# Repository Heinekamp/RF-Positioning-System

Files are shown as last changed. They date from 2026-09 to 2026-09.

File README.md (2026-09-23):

# RF-Positioning-System

A cost-effective 2-axis RF positioning system for characterizing antenna directionality in azimuth and elevation, developed as a bachelor project at the EMES chair at the University of Freiburg. Both axes rotate independently around a fixed centre of rotation, controlled by an ESP32 over a standard [SCPI](https://en.wikipedia.org/wiki/Standard_Commands_for_Programmable_Instruments) interface over Ethernet or USB.

<p align="center">
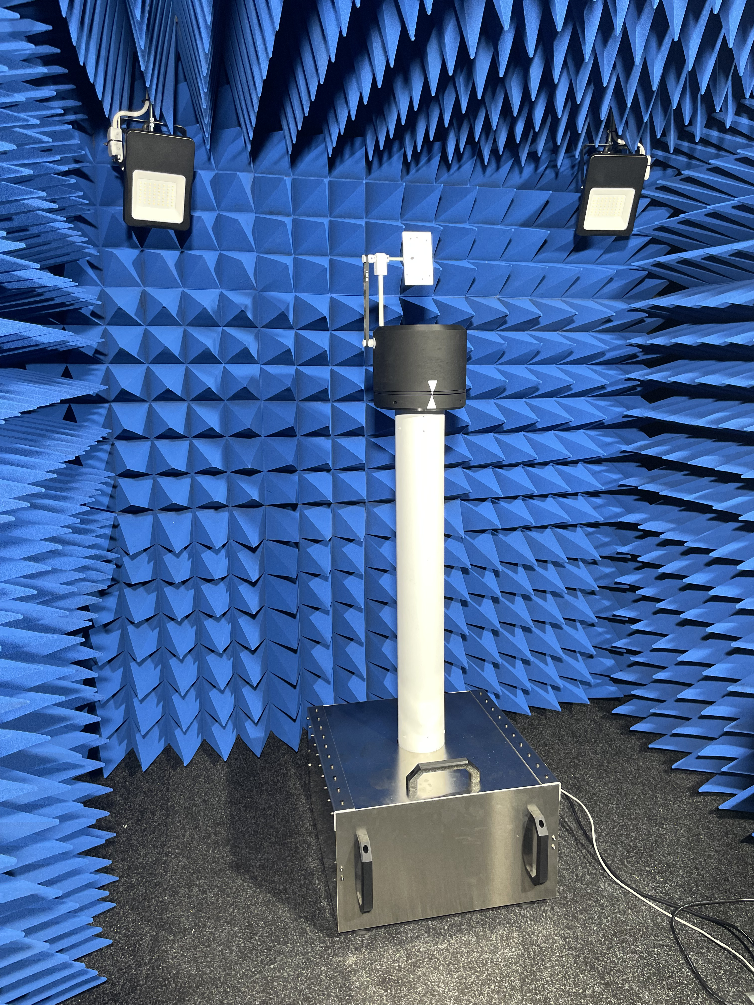
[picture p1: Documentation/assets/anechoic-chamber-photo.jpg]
RF-Positioning-System in an anechoic chamber
  
</p>

## Key Specifications

| Parameter | Value |
|---|---|
| Positioning range | 360° independent rotation, azimuth and elevation |
| Positioning accuracy | 1.0° |
| Positioning speed | 0.1°/s – 180°/s |
| Frequency range | 600 MHz – 6 GHz |
| Payload | 500 g |
| DUT height above base | 1.0 m |
| Base footprint | 40 cm × 40 cm |
| Total weight | ~20 kg |
| Communication | USB, Ethernet (SCPI) |
| Power supply | 12 V DC |

## Measured Performance

Repeatability of both rotation axes, measured with a motion-capture system across 10 repeated full revolutions:

<table>
<tr>
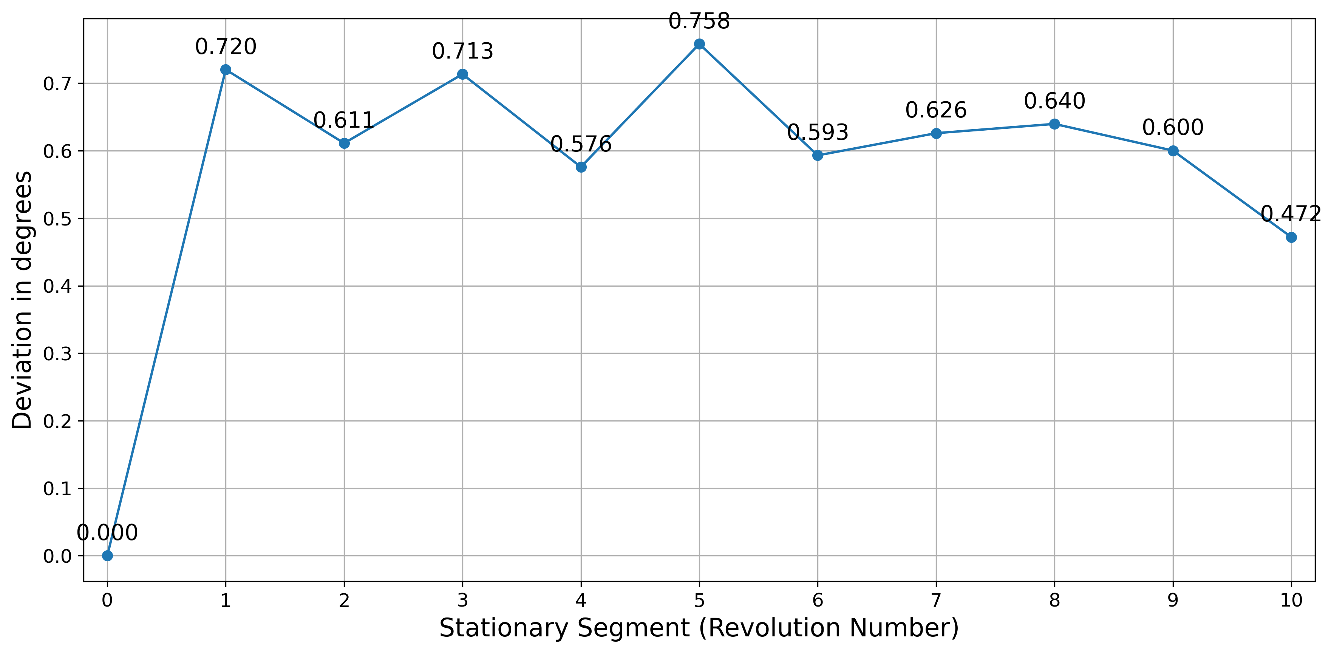
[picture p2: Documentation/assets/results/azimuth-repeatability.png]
Azimuth repeatability
<td width="50%"></td>
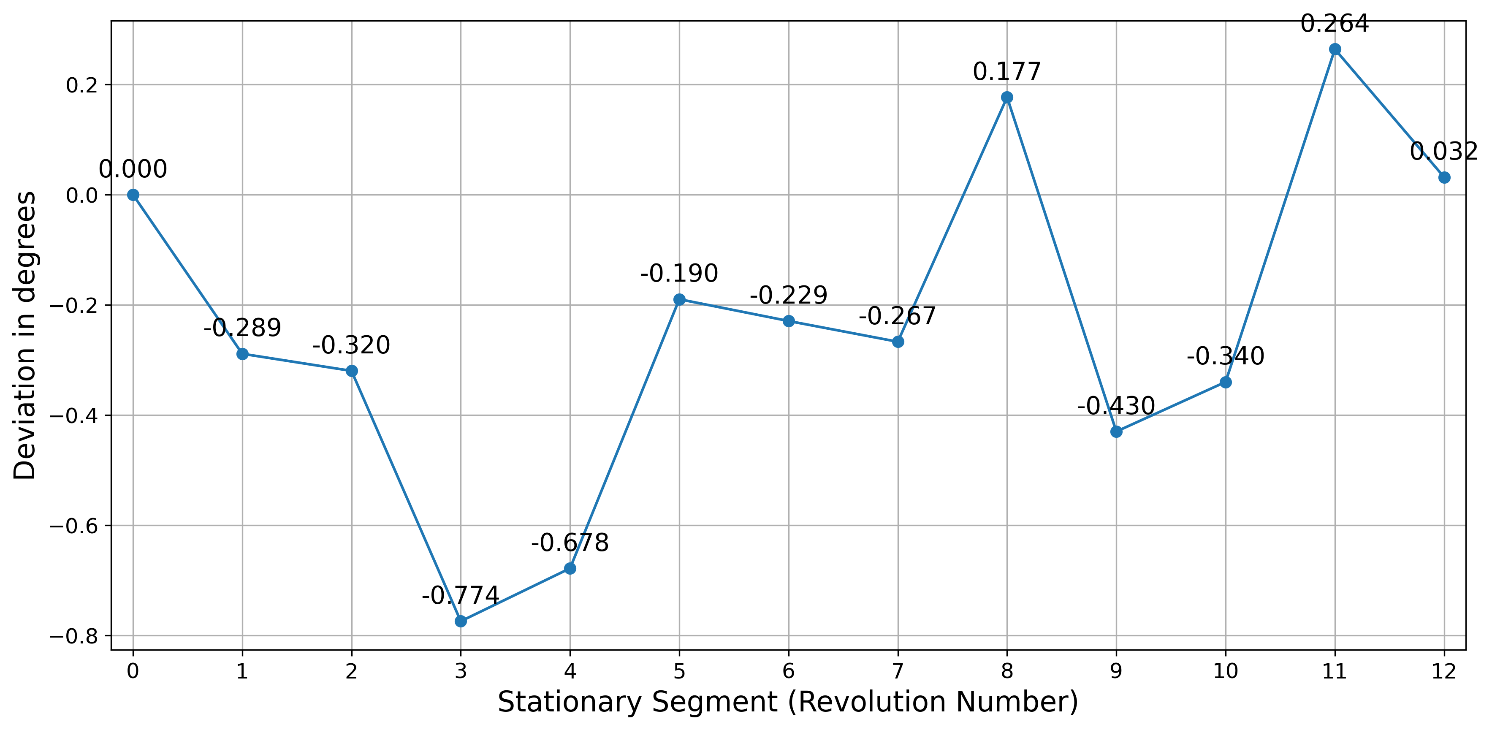
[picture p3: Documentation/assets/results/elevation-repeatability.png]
Elevation repeatability
<td width="50%"></td>
</tr>
<tr>
<td><sub>Azimuth positioning deviation from the commanded angle, measured after each of 10 repeated full revolutions.</sub></td>
<td><sub>Elevation positioning deviation from the commanded angle, measured the same way.</sub></td>
</tr>
</table>

Radiated emissions of the fully assembled, enclosed system were measured with the Ethernet link forced to 10&nbsp;Mbit/s, against 20 dB under the CISPR 11 Class B radiated emissions limit:

<table>
<tr>
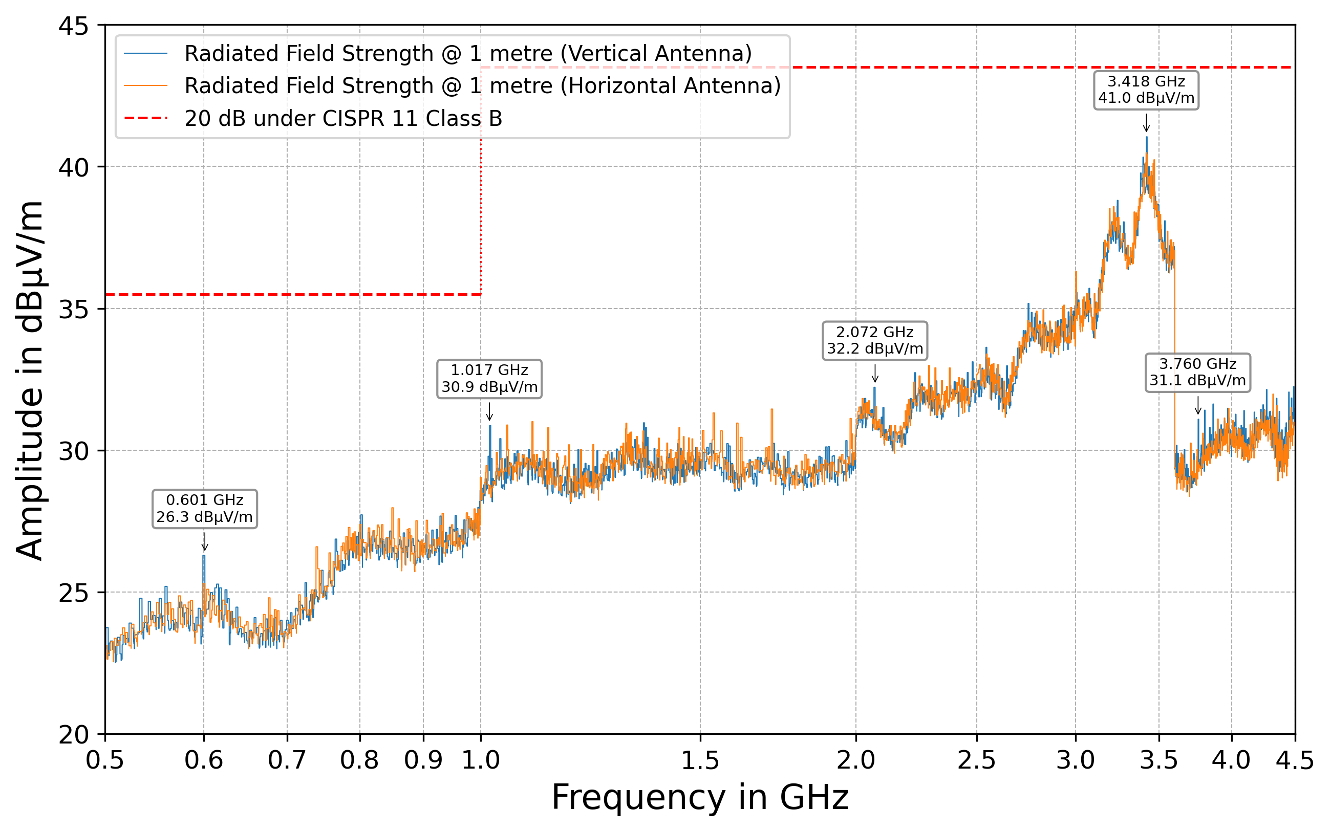
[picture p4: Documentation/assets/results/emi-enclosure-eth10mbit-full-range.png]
Radiated emissions, 0.5-4.5 GHz, enclosed system, 10 Mbit Ethernet
<td width="50%"></td>
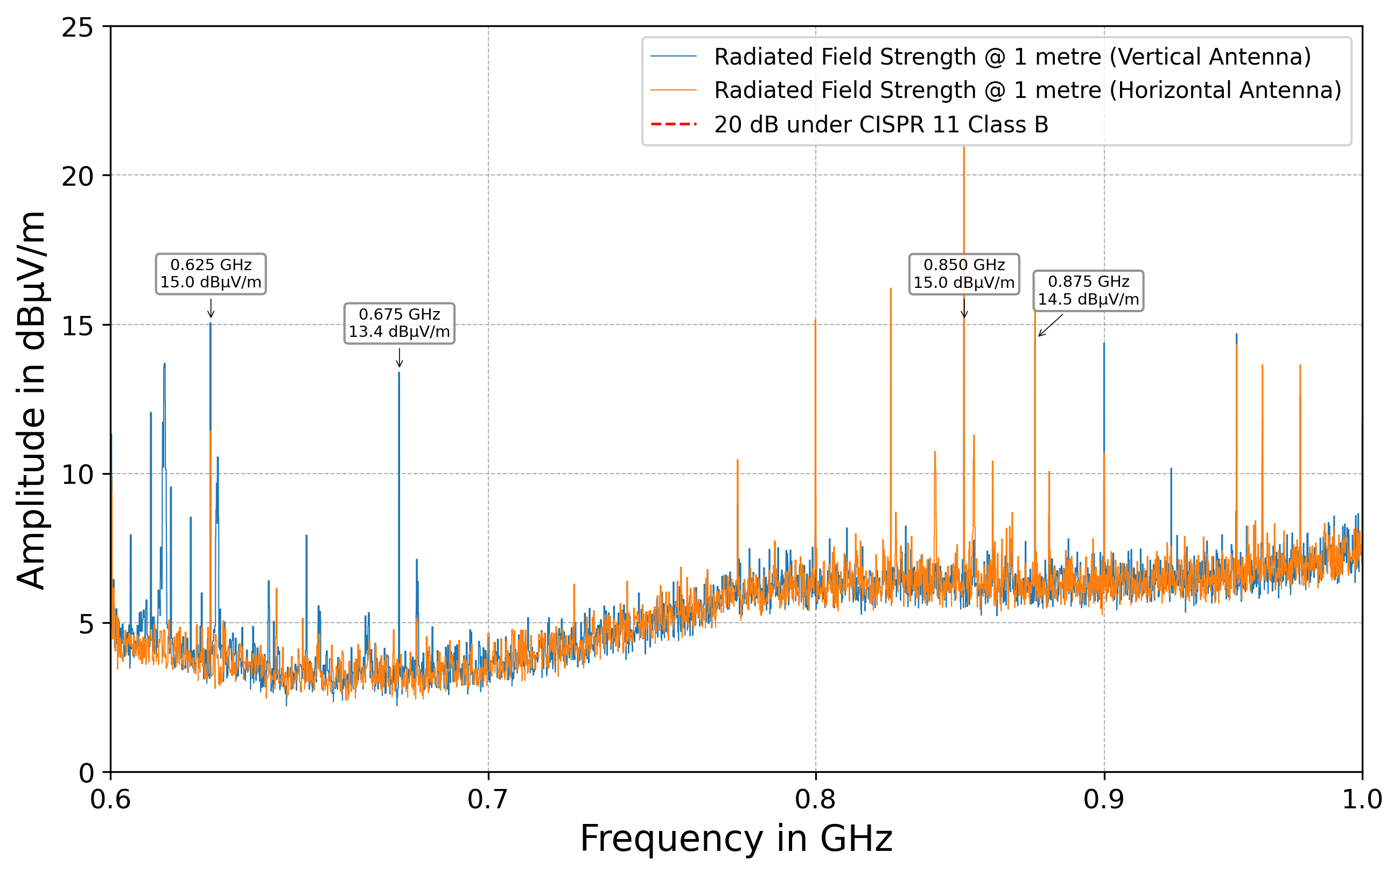
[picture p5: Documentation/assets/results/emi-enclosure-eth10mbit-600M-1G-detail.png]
Radiated emissions, 0.6-1.0 GHz detail
<td width="50%"></td>
</tr>
<tr>
<td><sub>Radiated field strength from 0.5–4.5 GHz, vertical and horizontal antenna polarization, against the CISPR 11 Class B limit.</sub></td>
<td><sub>Detail view of the 0.6–1.0 GHz band from the same measurement — individual emission peaks all remain more than 20 dB below the compliance limit shown at left.</sub></td>
</tr>
</table>

## Hardware

The controller is a custom PCB (KiCad project in [`Electrical/Controller`](Electrical/Controller)) built around an ESP32, driving two TMC2209 stepper drivers over UART. The mechanical design was done in Autodesk Fusion 360; the full CAD model is available in the [Fusion 360 online viewer](https://a360.co/42XAUax).

## Software

The firmware is written in C++ using the Arduino framework in PlatformIO (see [`Code/RF-Positioning-System`](Code/RF-Positioning-System)), and exposes a standards-compliant SCPI command set over Ethernet and USB — see that folder's [readme](Code/RF-Positioning-System/readme.md) for the full command reference and a quick-start example.

Firmware documentation is generated with Doxygen and published [here](https://heinekamp.github.io/RF-Positioning-System/index.html). If the following badge is green, it's up to date: .

## Documentation

The [Service Manual](Documentation/manual/ServiceManual.pdf) covers the system's theory of operation, the full SCPI interface, and maintenance/component-replacement procedures.

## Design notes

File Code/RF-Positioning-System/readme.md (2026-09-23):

# RF-Positioning System

The positioning system uses 2 stepper motors controlled by an ESP32 via SCPI over Ethernet to rotate the DUT in two axes.

## SCPI Command Reference

| Command | Description |
|---|---|
| `*IDN?` | Queries the identification string of the device. |
| `*RST` | Resets the device to its default state. |
| `*OPC?` | Returns 1 once all previously queued commands have completed. |
| `SYSTem:ERRor?` | Retrieves the last error from the error queue. |
| `SYSTem:HELP:HEADers?` | Provides a list of available SCPI commands. |
| `SYSTem:HELP:SYNTax?` | Returns detailed syntax help for a single command header. |
| `SYSTem:VERSion?` | Queries the firmware version of the device. |
| `SYSTem:DEBUG?` | Retrieves debug information from the system. |
| `SYSTem:PRESet` | Resets the system to its preset configuration. |
| `SYSTem:COMMunicate:ETHernet:PORT` | Sets the Ethernet communication port. |
| `SYSTem:COMMunicate:ETHernet:PORT?`| Queries the Ethernet communication port. |
| `SYSTem:COMMunicate:ETHernet:ADDRess` | Sets the IP address of the device. |
| `SYSTem:COMMunicate:ETHernet:ADDRess?`| Queries the IP address of the device. |
| `SYSTem:COMMunicate:ETHernet:MAC` | Sets the MAC address of the device. |
| `SYSTem:COMMunicate:ETHernet:MAC?`| Queries the MAC address of the device. |
| `SYSTem:COMMunicate:ETHernet:DGATeway?`| Queries the default gateway address. |
| `SYSTem:COMMunicate:ETHernet:RESET`| Resets the W5500 Ethernet module and re-initializes the network stack. |
| `CONTRol:ROTation:STEP#` | Jogs the specified axis one full revolution, for testing. |
| `CONTRol:ROTation:PERPetual#`  | Runs the specified axis continuously, for testing. |
| `CONTRol:ROTation:DIRection#`  | Sets the rotation direction for the DUT. |
| `CONTRol:ROTation:DIRection#?` | Queries the current rotation direction of the DUT. |
| `CONTRol:ROTation:RELative#` | Sets the relative position of the DUT. |
| `CONTRol:ROTation:ABSolute#` | Sets the absolute position of the DUT. |
| `CONTRol:ROTation:ABSolute#?`  | Queries the absolute position of the DUT. |
| `CONFigure:MOTor:RMScurrent` | Sets the RMS current for the stepper motors. |
| `CONFigure:MOTor:RMScurrent?`  | Queries the RMS current for the stepper motors. |
| `CONFigure:MOTor:HOLDcurrent`  | Sets the hold current for the stepper motors. |
| `CONFigure:MOTor:HOLDcurrent?` | Queries the hold current for the stepper motors. |
| `CONFigure:MOTor:MICROsteps` | Sets the microstepping configuration for the stepper motors. |
| `CONFigure:MOTor:MICROsteps?`  | Queries the microstepping configuration for the stepper motors. |
| `CONFigure:MOTor:SPEED` | Sets the motion speed used by subsequent moves. |
| `CONFigure:MOTor:SPEED?` | Queries the configured motion speed. |
| `CONFigure:MOTor:ACCELeration` | Sets the motion acceleration used by subsequent moves. |
| `CONFigure:MOTor:ACCELeration?`| Queries the configured motion acceleration. |
| `CONFigure:MOTor:STATus?` | Returns raw TMC2209 driver status registers for both axes. |
| `DIAGnostic:SESSion:LIST?` | Lists live SCPI sessions over Ethernet. |
| `DIAGnostic:SESSion:LOG?` | Lists recent SCPI session closures. |
| `DIAGnostic:SOCKet:LIST?` | Lists the raw state of all W5500 hardware sockets. |
| `DIAGnostic:SYSTem?` | Returns system and reset health diagnostics. |

For the full behavior, parameter ranges, and side effects of each command, see the [Service Manual](../../Documentation/manual/ServiceManual.pdf).

## Documentation
The full firmware documentation is available [here](https://heinekamp.github.io/RF-Positioning-System/index.html).

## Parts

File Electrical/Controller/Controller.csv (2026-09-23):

Reference | Value | Footprint | Datasheet | Qty | DNP | Exclude from BOM | Exclude from Board
A1 | ESP32 | FootprintLibrary:Adafruit_Feather_ESP32 | https://cdn-learn.adafruit.com/downloads/pdf/adafruit-huzzah32-esp32-feather.pdf | 1
C1,C10 | 2200uF | FootprintLibrary:WCAP-ATG8_16X25_DXL_ | ~ | 2
C2,C3,C5,C6,C13,C19 | 100nF | Capacitor_SMD:C_1206_3216Metric_Pad1.33x1.80mm_HandSolder | ~ | 6
C4,C7,C11 | 1000uF | FootprintLibrary:WCAP-ATUL_13X25_DXL_ | ~ | 3
C8 | 1uF | Capacitor_SMD:C_1210_3225Metric_Pad1.33x2.70mm_HandSolder | ~ | 1
C9,C15,C16 | 10uF | Capacitor_SMD:C_2220_5750Metric_Pad1.97x5.40mm_HandSolder | ~ | 3
C12,C17,C20 | 100uF | FootprintLibrary:WCAP-ATG8_6.3X11_DXL_ | ~ | 3
C14,C18 | 10nF | Capacitor_SMD:C_1206_3216Metric_Pad1.33x1.80mm_HandSolder | ~ | 2
C21 | 1nF | Capacitor_SMD:C_1206_3216Metric_Pad1.33x1.80mm_HandSolder | ~ | 1
D1 | SMCJ36CA | Diode_SMD:D_SMC_Handsoldering | ~ | 1
FL1,FL2,FL3,FL4 | 744235900 | FootprintLibrary:WE-CNSW_1812 | https://www.we-online.com/components/products/datasheet/744235900.pdf | 4
J1 | 12-28V IN | FootprintLibrary:BarrelJack_Wuerth_6941xx301002 | ~ | 1
J2 | Screw_Terminal_01x02 | FootprintLibrary:691502710002 | ~ | 1
J3,J4 | RJ45_LED_Shielded | FootprintLibrary:Wuerth 615008137421 | ~ | 2
L1,L2,L3,L4 | 600Ω@100 MHz | Capacitor_SMD:C_2220_5750Metric_Pad1.97x5.40mm_HandSolder | ~ | 4
Q1 | DMT10H015LK3-13 | Package_TO_SOT_SMD:TO-252-3_TabPin2 | https://www.diodes.com/assets/Datasheets/DMT10H015LK3.pdf | 1
Q2 | DMN53D0LW-7 | Package_TO_SOT_SMD:SOT-323_SC-70_Handsoldering | https://www.onsemi.com/pub/Collateral/BSS138-D.PDF | 1
R1 | 1k | Resistor_SMD:R_1206_3216Metric_Pad1.30x1.75mm_HandSolder | ~ | 1
R2 | 6.04k | Resistor_SMD:R_1206_3216Metric_Pad1.30x1.75mm_HandSolder | ~ | 1
R3 | 10k | Resistor_SMD:R_1206_3216Metric_Pad1.30x1.75mm_HandSolder | ~ | 1
R4 | 604k | Resistor_SMD:R_1206_3216Metric_Pad1.30x1.75mm_HandSolder | ~ | 1
R5 | 76.8k | Resistor_SMD:R_1206_3216Metric_Pad1.30x1.75mm_HandSolder | ~ | 1
R6 | 20k | Resistor_SMD:R_1206_3216Metric_Pad1.30x1.75mm_HandSolder | ~ | 1
U1,U2 | TMC2209 | FootprintLibrary:BTT-TMC2209-V1.3 | https://github.com/bigtreetech/BIGTREETECH-TMC2209-V1.2/blob/master/manual/TMC2209-V1.2-manual.pdf | 2
U3 | TPS26631PWP | Package_SO:HTSSOP-20-1EP_4.4x6.5mm_P0.65mm_EP3.4x6.5mm_Mask2.75x3.43mm_ThermalVias_HandSolder | https://www.ti.com/lit/ds/symlink/tps2663.pdf | 1
U5 | LD1086D2M33TR | FootprintLibrary:TO-220-3_Vertical-v8508a | https://www.st.com/resource/en/datasheet/ld1086.pdf | 1

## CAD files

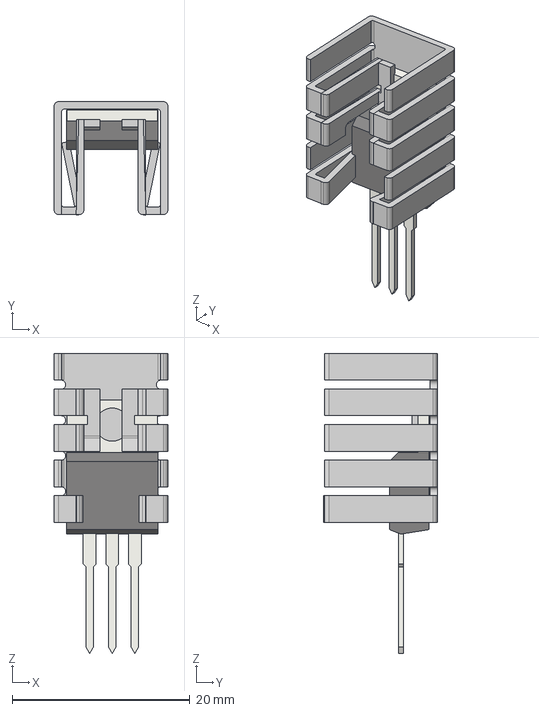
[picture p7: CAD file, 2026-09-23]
Electrical/Controller/3D-models/TO-220-3_Vertical v8508a.step
12.8 x 12.8 x 33.8 mm

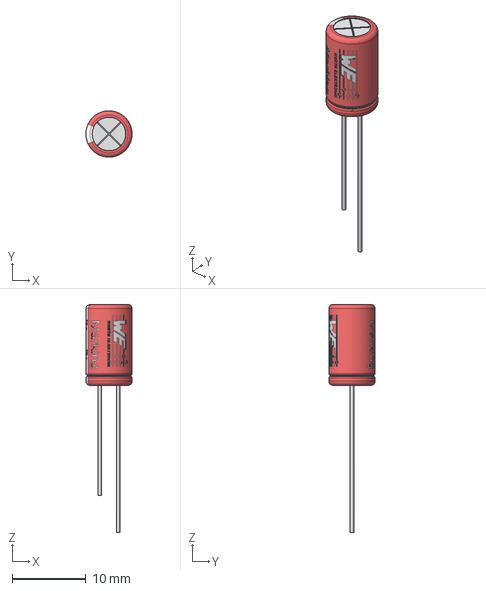
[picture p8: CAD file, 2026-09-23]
Electrical/Controller/3D-models/Download_STP_86001xx730xx (rev1).stp
6.29 x 6.30 x 31.0 mm

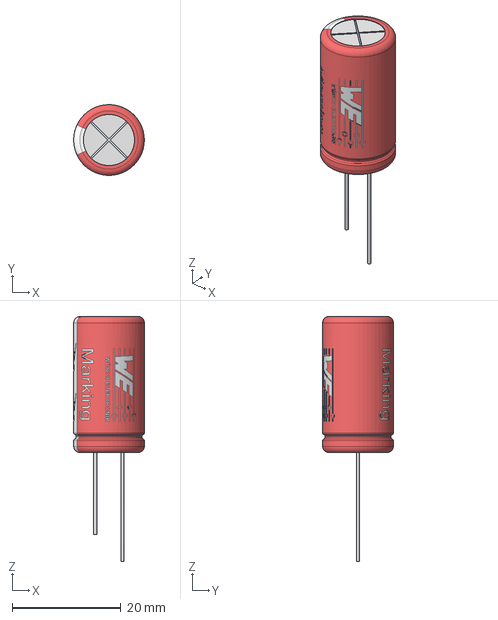
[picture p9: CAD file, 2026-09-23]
Electrical/Controller/3D-models/Download_STP_860040x7801x (rev1).stp
13.0 x 13.0 x 45.0 mm

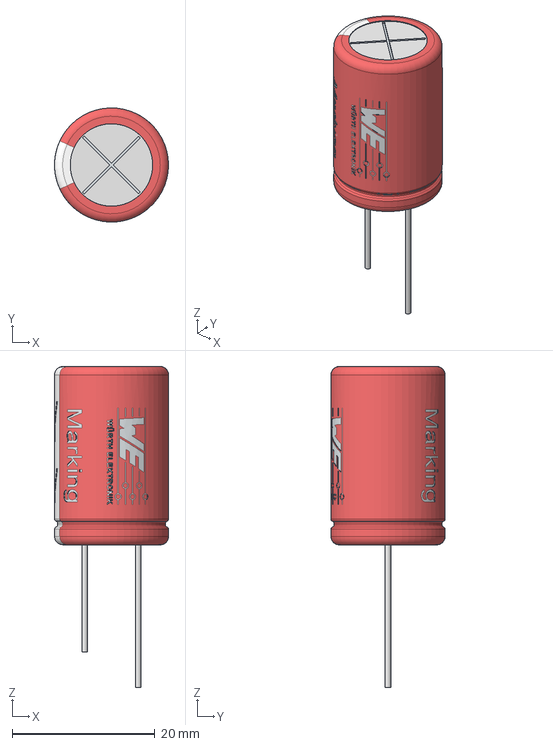
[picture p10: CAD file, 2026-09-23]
Electrical/Controller/3D-models/Download_STP_86001xx800xx (rev1).stp
16.0 x 16.0 x 45.0 mm

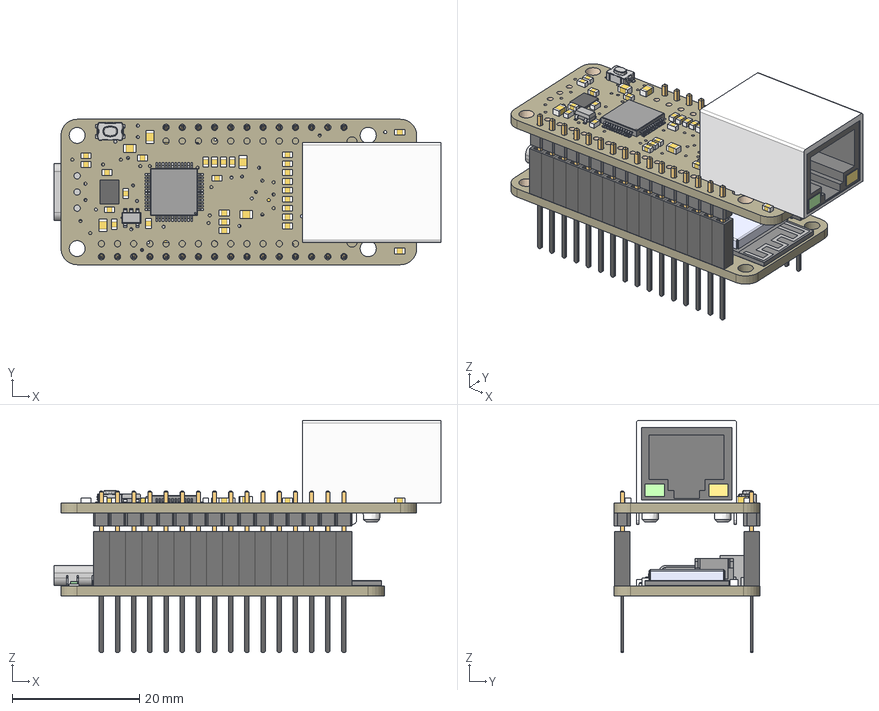
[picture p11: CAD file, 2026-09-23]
Electrical/Controller/3D-models/5400 ESP32 Feather V2 v2.step
60.8 x 22.9 x 36.5 mm
Board
10uF x 7
AP2112-3.3 x 2
MBR540
JSTPH
MCP73831T-2ACI/OT
RED x 2
1uF x 15
KMR2 x 2
DMG3415U
47K x 2
ESP32-PICO-MINI-02MINI
WS2812B3535
STEMMA_I2C_QTRA
TPB1,27 x 2
USB Type C
CP2102N-24
DUAL NPN
Komponente1 x 12
Komponente2 x 12
Komponente1_1 x 16
Komponente2_1 x 16
Board_1
W5500
RB1-125BAG1A
25MHz
10K x 27
ferrite x 5
74AHC1G125
KMR2_1
6130xx11121_PIN x 12
6130xx11121_PIN_1 x 16

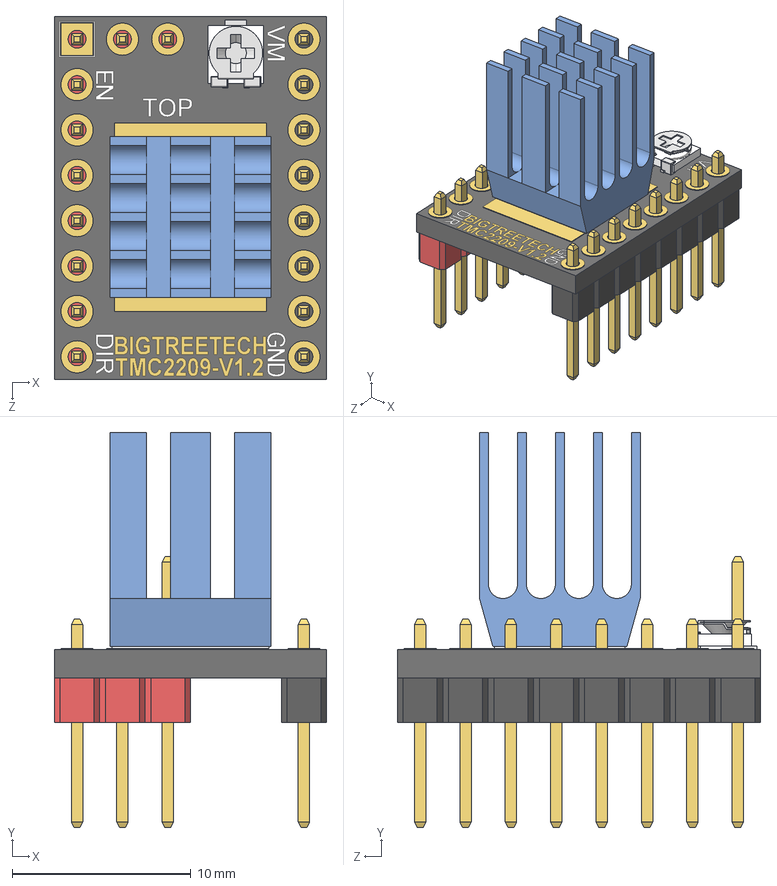
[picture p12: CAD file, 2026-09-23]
Electrical/Controller/3D-models/BTT TMC2209-V1.2.STEP
15.2 x 22.1 x 20.3 mm
TMC2209_board
Pin_Header_1x2_red
Pin_Header_1x8_red
Pin_Header_1x8_black
EVM-3E___ _________
TMC2209_heatsink

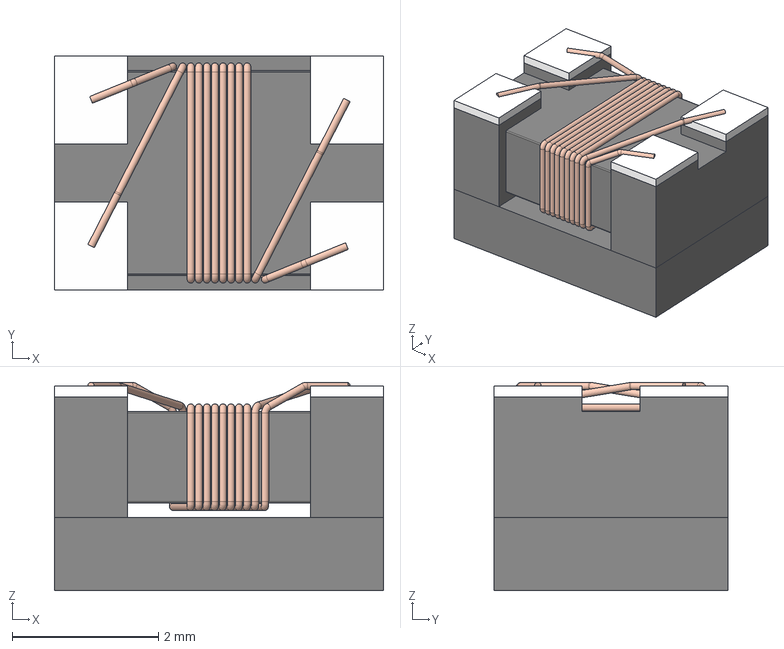
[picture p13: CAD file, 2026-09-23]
Electrical/Controller/3D-models/WE-CNSW_1812.step
4.50 x 3.20 x 2.85 mm

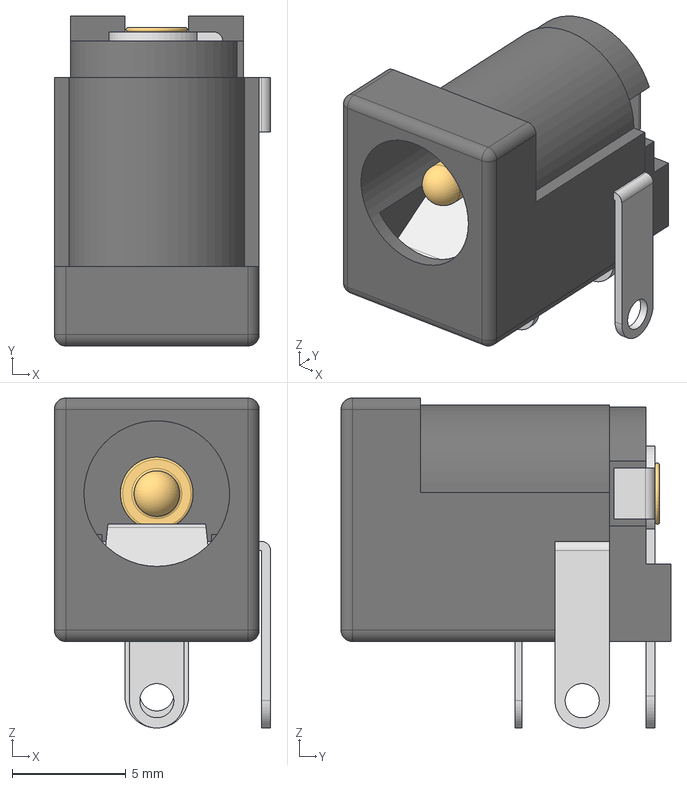
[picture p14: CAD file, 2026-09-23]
Electrical/Controller/3D-models/694106301002 (rev1).stp
9.50 x 14.5 x 14.5 mm
6941xx301002
694106301002_PinContact
6941xx301002_Back
6941xx301002_PinContact2
6941xx301002_PinLame
6941xx301002_PinBis

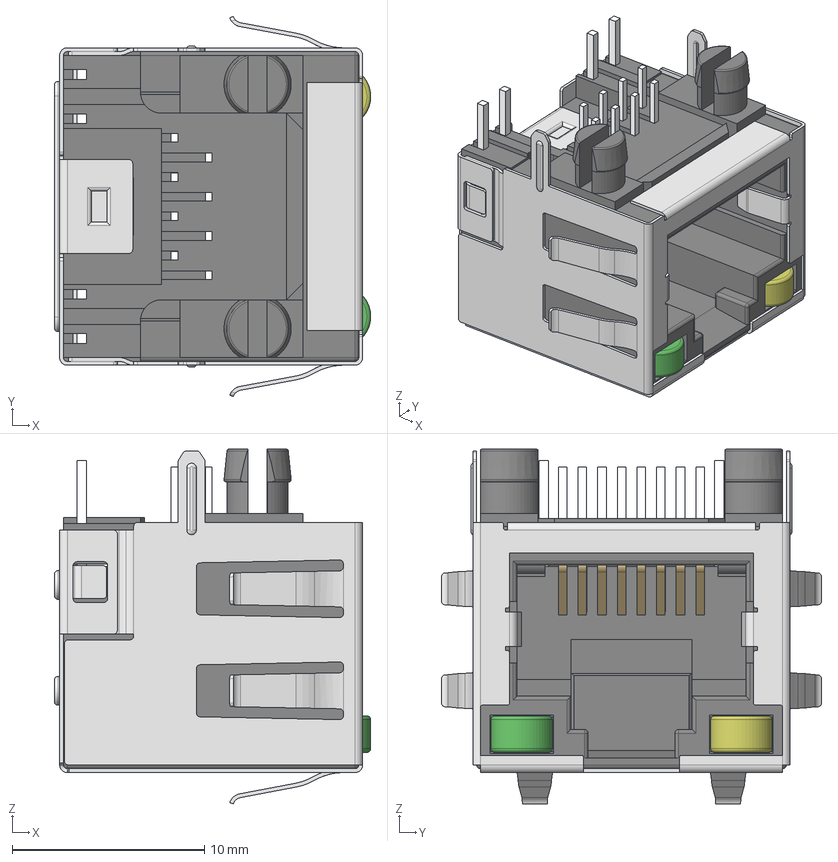
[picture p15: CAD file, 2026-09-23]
Electrical/Controller/3D-models/615008137421.step
16.4 x 19.8 x 18.4 mm
Shielding
Pin_short x 4
Gehäuse
LED_yellow
Halter_Pin
LED_green
Deckel
Pin_long x 4

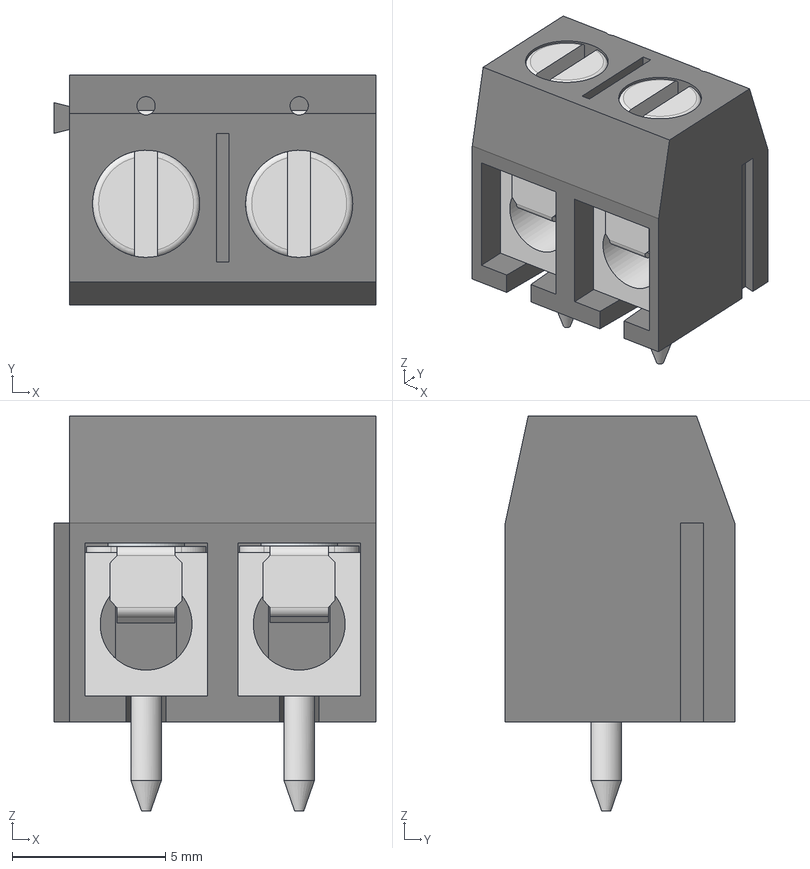
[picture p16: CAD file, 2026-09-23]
Electrical/Controller/3D-models/691502710002 (rev1).stp
10.5 x 7.50 x 12.9 mm
6915027100xx_CAGE x 2
6915027100xx_PIN x 2
6915027100xx_VIS x 2

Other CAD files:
Electrical/Controller/3D-models/691502710002.step

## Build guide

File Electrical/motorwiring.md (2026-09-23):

Ethernet to JST PH motor connector wiring guide:

Pin 1   | Orange + Green
Pin 2   | X
Pin 3   | Brown + Blue / White
Pin 4   | Orange / White + Green / White
Pin 5   | X
Pin 6   | Brown / White + Blue

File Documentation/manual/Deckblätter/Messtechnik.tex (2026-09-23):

%% Titlepage Messtechnik
\begin{titlepage}
    \vspace*{-2cm}
    \begin{centering}
        \begin{minipage}{1.2\textwidth}
            \hspace{-0cm}
            \begin{minipage}[b]{0.25\textwidth}
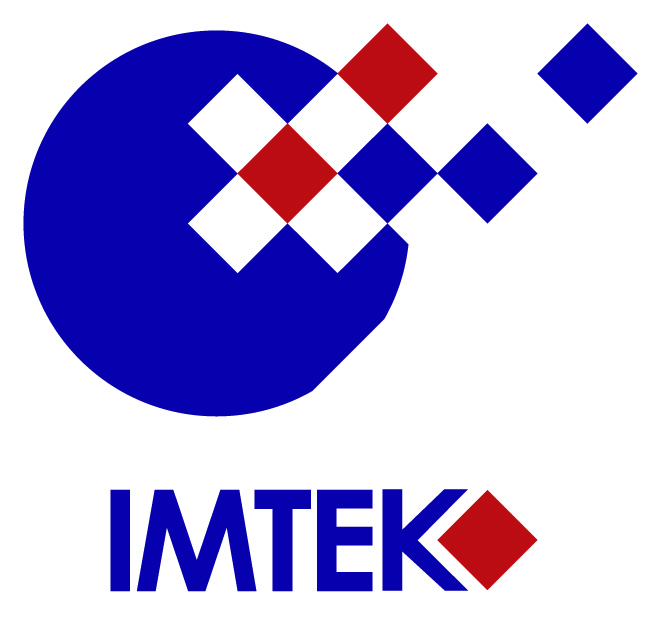
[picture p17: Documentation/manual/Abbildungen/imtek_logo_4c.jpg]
                
            \end{minipage}
            \hspace*{2.3cm}
            \begin{minipage}[t]{0.9\textwidth}
                
            \end{minipage}
        \end{minipage}
        \vspace{2cm}
        \newline
        {\Huge RF Positioning System \par}
        	\vspace{0.5cm}
        {\huge Service Manual \par}
        	\vspace{0.5cm}
    \end{centering}

    \vspace{0cm}
    \begin{center}
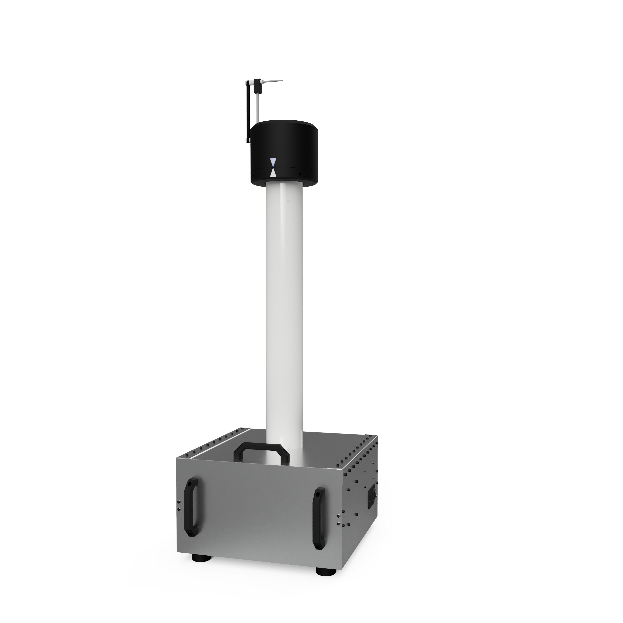
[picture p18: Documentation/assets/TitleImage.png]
        
    \end{center}

    \hspace*{-0.4cm}
    \renewcommand{\arraystretch}{2}
    \begin{tabular}{p{0.2\textwidth} p{0.8\textwidth}}
        \Large Date: & \Large \today\\
        \Large Author: & \Large Max Heinekamp \\
    \end{tabular}
    \enlargethispage{2\baselineskip}
    \renewcommand{\arraystretch}{1}
    \vspace{1cm}
    \newline
    \normalsize 
    %[Abstract here]
    \vfill
\end{titlepage}

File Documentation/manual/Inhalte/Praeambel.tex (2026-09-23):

%% Input Codec
\usepackage[utf8]{inputenc}

%% Sprache (Silbentrennung etc.)
\usepackage[british]{babel}

%% Font Codec
\usepackage[T1]{fontenc}

\usepackage[useregional=numeric]{datetime2}

\usepackage[lowtilde]{xurl}

%% Literaturverzeichnis
\usepackage[style=numeric-comp,sorting=none]{biblatex}
%\usepackage[english=guillemets]{csquotes}
\addbibresource{Literaturverzeichnis/Literaturverzeichnis.bib} 
\setcounter{biburllcpenalty}{7000}
\setcounter{biburlucpenalty}{8000}

%% Bearbeitung von Kopf und Fußzeile
\usepackage{fancyhdr}
\fancyhf{}
\pagestyle{fancy}
\fancyheadoffset{0cm}
\fancyfoot[R]{\thepage}

%% Paket für die Verwendung von Einheiten
\usepackage[separate-uncertainty=true]{siunitx}

%% "Punktlinien" im Inhaltsverzeichnis
\usepackage{tocloft}
\renewcommand{\cftsecleader}{\cftdotfill{\cftdotsep}}

%% Seitenabstaende
\usepackage[left=2.5cm,right=2.5cm,top=1.25cm,bottom=1.25cm,includeheadfoot]{geometry} 

%% Math Features
\usepackage{amsmath}
\usepackage{amsfonts}
\usepackage{amssymb}

%% Grafik Features
\usepackage{graphicx}
\usepackage{tikz}
\usetikzlibrary{positioning}
\usepackage[inkscapeformat=png]{svg}

%% Zeilenabstand 1,5-fache Kegelhöhe
\usepackage{setspace} \onehalfspacing

%% Größerer Abstand zwischen Tabellenüberschrift und Tabelle
\usepackage{caption}
\captionsetup[table]{position=above,skip=0.5cm}

%% Nicht einrücken
\setlength{\parindent}{0em}

%% Bearbeitung von Tabellen
\usepackage{booktabs}
\usepackage{ltablex} %was tabularx
\keepXColumns   % used with ltablex and geometry

\usepackage{wrapfig}
\usepackage{float}

%% Syntax Highlighting
\usepackage{listings}

%% Links und Verweise
\usepackage[hidelinks]{hyperref}

\definecolor{codegreen}{rgb}{0,0.6,0}
\lstdefinestyle{mystyle}{
    basicstyle=\ttfamily\footnotesize,
    backgroundcolor=\color{white},
    commentstyle=\color{codegreen},
    keywordstyle=\color{blue},
    numberstyle=\tiny\color{gray},
    stringstyle=\color{red},
    breakatwhitespace=false,         
    breaklines=true,                 
    captionpos=b,                    
    keepspaces=true,                 
    numbers=left,                    
    numbersep=5pt,                  
    showspaces=false,                
    showstringspaces=false,
    showtabs=false,                  
    tabsize=2
}

\lstset{style=mystyle}

%Subfigures
\usepackage{subcaption}

%urldate
\DeclareFieldFormat{urldate}{%
  (Accessed: \thefield{urlday}.%
  {\thefield{urlmonth}}.%
  \thefield{urlyear}\isdot)}

\usepackage{mdframed}
\usepackage{csquotes}

\usepackage{pdfpages}

\usepackage{array}
\newcolumntype{L}{>{\centering\arraybackslash}m{4.5cm}}
\newcolumntype{C}{>{\centering\arraybackslash}m{2.5cm}}

\usepackage{multicol}

\usepackage[most]{tcolorbox}
\usepackage{fontawesome5} % for icons
\usepackage{xcolor}

% Generic github-style box template
\tcbset{
  githubbox/.style 2 args={
    standard jigsaw,
    opacityback=0,
    opacityframe=0,
    enhanced,
    sharp corners,
    boxrule=0pt,
    colback=white,
    colframe=white,
    borderline west={2pt}{0pt}{#1},
    before skip=10pt, after skip=10pt,
    % Remove title bar, place title inside box
  }
}

% Macro to render colored title line inside the box
\newcommand{\githubboxtitle}[2]{%
  {\color{#1}\bfseries #2}\\[2pt]
}

% Define individual boxes using the style, with title inside
\newtcolorbox{notebox}{
  githubbox={blue}{},
  before upper={\githubboxtitle{blue}{\faInfoCircle\quad Note}}
}

\newtcolorbox{tipbox}{
  githubbox={green!60!black}{},
  before upper={\githubboxtitle{green!60!black}{\faLightbulb[regular]\quad Tip}}
}

\newtcolorbox{importantbox}{
  githubbox={violet}{},
  before upper={\githubboxtitle{violet}{\faExclamationCircle\quad Important}}
}

\newtcolorbox{warningbox}{
  githubbox={orange!90!black}{},
  before upper={\githubboxtitle{orange!90!black}{\faExclamationTriangle\quad Warning}}
}

\newtcolorbox{cautionbox}{
  githubbox={red}{},
  before upper={\githubboxtitle{red}{\faTimesCircle\quad Caution}}
}

\usepackage{enumitem}

% Assembly instructions box
% Define part colors
\definecolor{part1}{RGB}{255, 85, 85}
\definecolor{part2}{RGB}{85, 170, 255}
\definecolor{part3}{RGB}{85, 255, 85}
\definecolor{part4}{RGB}{255, 170, 0}

% Tool pictogram mockups
\newcommand{\flathead}[1]{%
  \renewcommand{\arraystretch}{0.25}
  \begin{tabular}{c}
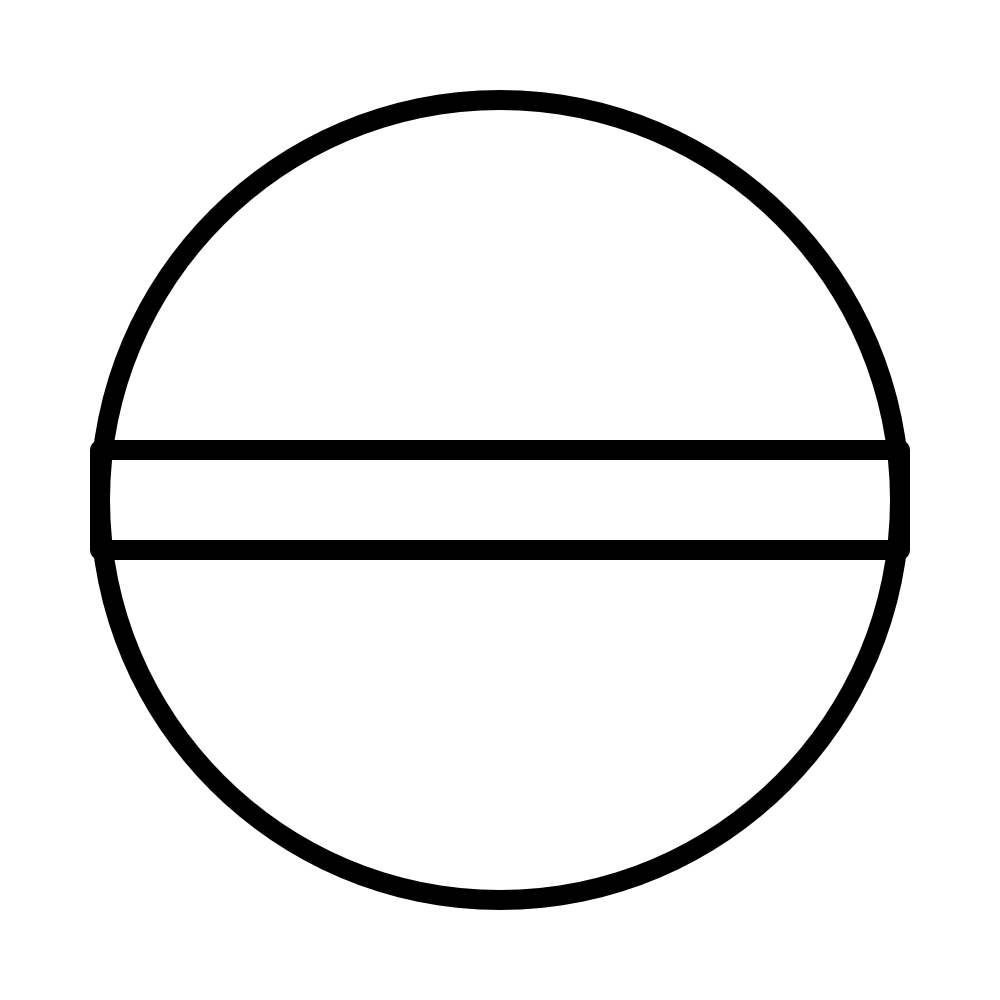
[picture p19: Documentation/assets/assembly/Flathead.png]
     \\
    \tiny #1
  \end{tabular}
}
\newcommand{\hexkey}[1]{%
  \renewcommand{\arraystretch}{0.25}
  \begin{tabular}{c}
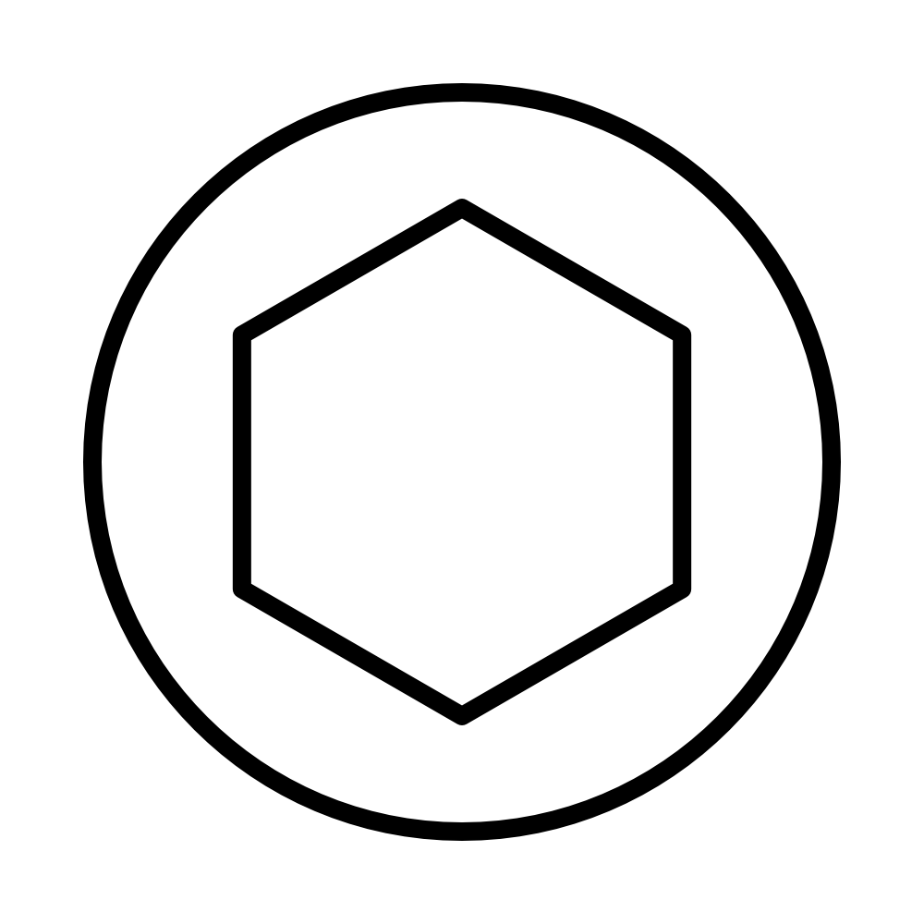
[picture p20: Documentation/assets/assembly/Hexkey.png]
     \\
    \tiny #1
  \end{tabular}
}

\newcommand{\torx}[1]{%
  \renewcommand{\arraystretch}{0.25}
  \begin{tabular}{c}
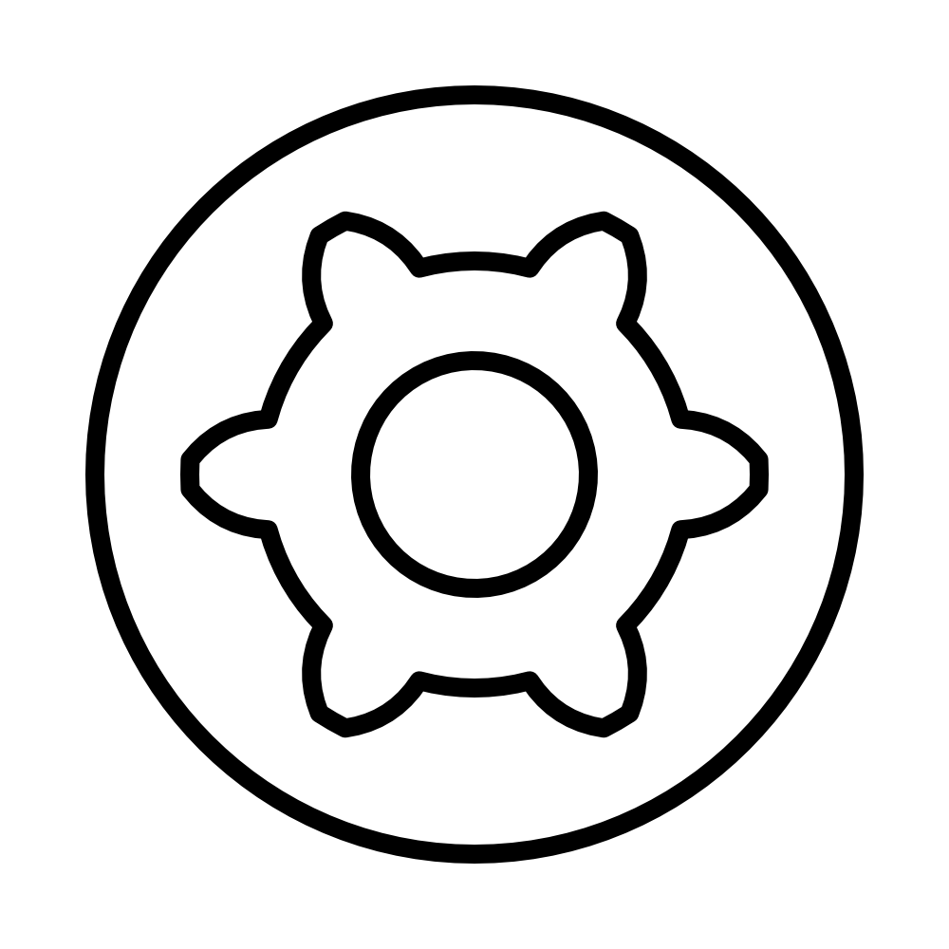
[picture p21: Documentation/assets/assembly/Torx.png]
     \\
    \tiny #1
  \end{tabular}
}

\newcommand{\smartphone}[1]{%
  \renewcommand{\arraystretch}{0.25}
  \begin{tabular}{c}
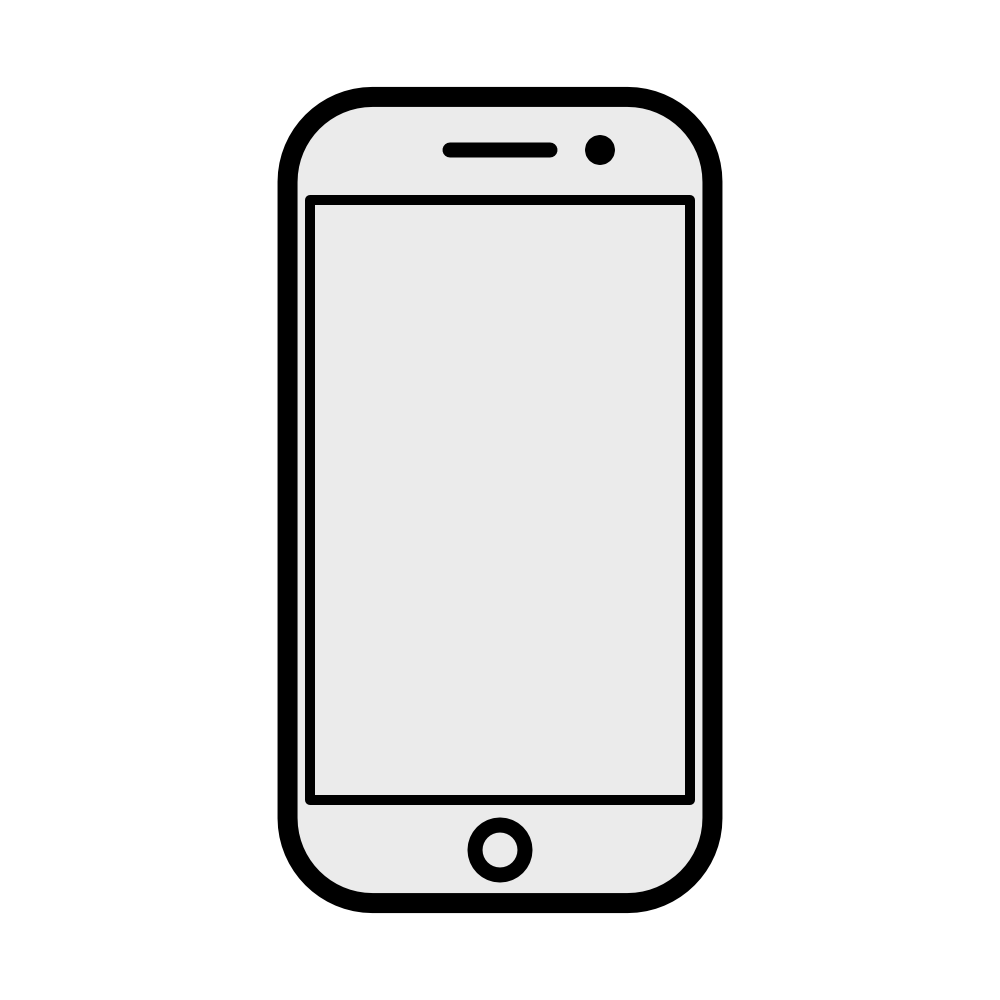
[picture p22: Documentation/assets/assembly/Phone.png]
     \\
    \tiny #1
  \end{tabular}
}

% Colored bullet item command
\newcommand{\partitem}[2]{\item[\textcolor{#1}{\textbullet}] #2}

% Assembly step macro
\newcommand{\assemblystep}[4]{%
  \noindent
  \begin{tikzpicture}[remember picture]
    % Outer box
    \draw (0,0) rectangle (16,-10);

    % Step number
    \node[anchor=north west] at (0,-0.2) {\textbf{Step #1}};

    % Tools section
    \node[anchor=north west] at (10.3,0.1) {#3};
    \draw (10,0) -- (10,-1) -- (16,-1);

    % Image area
    \draw (0,-1) -- (10,-1) -- (10,-10);
    \node at (5,-5.5) {};

    % Parts and instructions node
    \node[anchor=north west, text width=5.5cm, align=left] at (10.3,-1) {\small{#4}};
  \end{tikzpicture}
}

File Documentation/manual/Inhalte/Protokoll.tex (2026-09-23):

\fancyhead[L]{RF-Positioning System}
\newpage

\section{Introduction}

This document describes the RF-Positioning System, a cost-effective two-axis antenna positioner with a small footprint, intended for characterizing antenna directionality in azimuth and elevation around a fixed centre of rotation. It covers the system's operating principles, its SCPI interface, and the maintenance and service procedures needed to keep it running.

\section{Specifications \& Requirements}

The RF-Positioning System is built to the following specifications \cite{timothy_foley_low-cost_2017, maturo_gmbh_ota_nodate, innco_systems_gmbh_de3600_nodate, microwave_vision_group_light_2025, ets-lindgren_2117_nodate, tdk_rf_solutions_3-dimensional_2024}:
\begin{itemize}
    \item \textbf{Positioning Range:} \SI{360}{\degree} independent rotation in azimuth and elevation
    \item \textbf{Positioning Accuracy:} \SI{1.0}{\degree}
    \item \textbf{DUT Height above Base:} \SI{1.0}{\meter}
    \item \textbf{Base Footprint:} \SI{40}{\centi\meter} x \SI{40}{\centi\meter}
    \item \textbf{Minimum Positioning Speed:} \SI{0.1}{\degree/\second}
    \item \textbf{Maximum Positioning Speed:} \SI{180}{\degree/\second}
    \item \textbf{Payload:} \SI{500}{\gram} 
    \item \textbf{Frequency Range:} \SI{600}{\mega\hertz}~\textendash~\SI{6}{\giga\hertz} 
    \item \textbf{Communication:} USB, Ethernet
    \item \textbf{Power Supply:} \SI{12}{\volt} DC
    \item \textbf{Total Weight:} \SI{\sim 20}{\kilo\gram}
\end{itemize}

\section{Theory of Operation}

\subsection{Mechanical Design}
Most commercial designs opt to only implement elevation rotation on the mast and use a large turntable to provide azimuth rotation. In order to maintain a smaller footprint, while still keeping the centre of mass of the DUT constant during rotation, this design has moved the azimuth rotation to the top of the mast. Figure \ref{fig:mechanical_design} shows how this is achieved using two shafts to transfer the rotation from the motors to the top of the mast. 

In the base unit, both shafts are kept in place by a set of bearings. The stepper motors are coupled to the shafts using a set of timing belts. 

The shaft for the azimuth rotation is mounted off centre and has a gear mounted to the top end, which interfaces with a negative gear on the inside of the head unit. Meanwhile, the elevation shaft is mounted in the centre of the mast aligned with the azimuth axis of rotation. At the top of the shaft, a set of bevel gears is used to transfer the rotation out of the side of the head unit. From there, another timing belt is used to transfer the rotation to the top of the secondary mast, where the DUT is mounted.

The main drawback to this design is that the elevation rotation is coupled to the azimuth rotation. This adds some complexity to the control algorithm, as in order to maintain the elevation angle when the azimuth angle is changed, the elevation motor needs to be moved in sync with the azimuth motor. 

\begin{figure}[h!]
    \centering
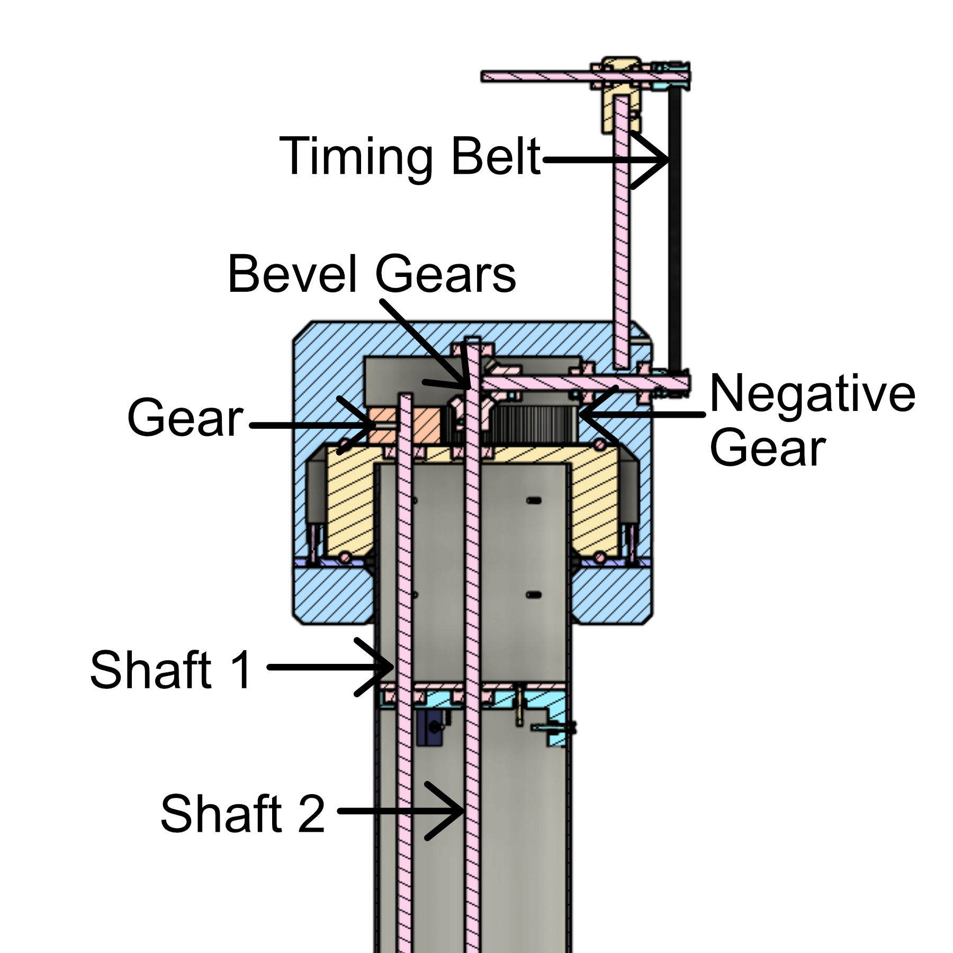
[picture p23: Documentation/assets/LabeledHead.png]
    
    \caption{Labelled rotation mechanism in the head unit.}
    \label{fig:mechanical_design}
\end{figure}

\subsection{Choice of Materials}
Under the main objective of using only non-conductive materials outside of the base, material choice was driven by the need to balance a low dielectric constant, to minimize interference with RF measurements, with high mechanical strength.

Polylactic Acid (PLA) was chosen for the 3D printed components, which make up most of the head unit, as well as the shaft stabilizers in the pipe. In 2018, Veseleý et al. measured in \cite{vesely_evaluation_2018} that 3D Printed PLA had a dielectric constant $\epsilon_r$ of slightly less than 2.0, for frequencies from 1kHz to 100kHz, with the trend showing a slight decrease for higher frequencies. It should be noted that these values were measured for a frequency range much lower than the RF frequencies used in this project. However, it is assumed that the dielectric constant will not increase significantly for higher frequencies. Additionally, these values were measured for parts with an infill density of \SI{100}{\percent}, while the parts in this project were printed with an infill density of \SI{20}{\percent}. This should significantly reduce the dielectric constant, as \SI{80}{\percent} of the material is replaced with air. Therefore, an $\epsilon_r$ of 2.0 should give a sufficient worst case estimate for the dielectric constant of the 3D printed parts.

For the printed parts fixing the pipe and the motors to the base, a higher strength material was required. As this would be in the shielded base, the dielectric constant is not critical. For this reason, a polyamide with carbon fibre reinforcing particles (PA-CF) was chosen for the additional strength and rigidity. Compared to the PLA, the PA-CF has significantly larger flexural modulus\footnote{Stiffness of the material when bent, a larger value indicates a stiffer material.} (\SI{8.0}{\giga\pascal} vs. \SI{3.2}{\giga\pascal}) as well as a higher charpy impact strength\footnote{The charpy impact strength describes the amount of energy a material can absorb under flexural shock (being struck by a hammer) before breaking.} (\SI{60}{\kilo\joule\per\square\metre} vs. \SI{13}{\kilo\joule\per\square\metre})\cite{formfutura_bv_technical_2023},\cite{prusa_polymers_technical_2022}. It should however be noted, that the conductive carbon fibres in the PA-CF, which provide the additional stiffness, may have a negative effect on the signal integrity, which makes the material unsuitable for use in the RF path.

Another area where material choice was critical, are the fasteners used in the head unit. For the majority of these fasteners, polyamide screws were chosen, as they are commercially available at a low cost. Polyamide typically has a dielectric constant of 3.5 at \SI{1}{\mega\hertz} in dry conditions. However, the material is highly hygroscopic, which means that this value increases up to 7.0 at \SI{50}{\percent} humidity \cite{rolec_gehause-systeme_gmbh_polyamid_pa6_en-_nodate}. This is not ideal, however still significantly better than using metal screws. If there were commercially available screws made from a less hygroscopic material that still fulfil the strength requirements this would be an area where the design could be further improved. For the grub screws used to secure the gears to the shafts, a plastic screw would not provide sufficient strength to keep the gears from slipping on the shaft. For this reason, steel screws with a diameter of \SI{4}{\milli\metre} and a length of \SI{5}{\milli\metre} were chosen. The dimensions here are critical, as the longest side is equivalent to $\lambda/10$ for the maximum frequency of \SI{6}{\giga\hertz} used in this project, which means that it will not significantly interfere with the RF measurements. This is due to the fact that objects smaller than $\lambda/10$ predominantly interact with the RF signals through Rayleigh scattering \cite{nave_blue_nodate}.
																			
\subsection{Motors \& Drivers}
The positioning system uses stepper motors, as these provide accurate positioning at a low cost without needing a closed loop feedback system. The motors are driven using Trinamic TMC2209 stepper motor drivers, which offer a large number of optional features, accessible over their UART interface. One of the features is StallGuard4™ collision detection. As it is not possible to add sensors for a closed loop feedback system in the head unit without running metal wires through the RF path, this feature can give a good indication when a rotational axis has gotten stuck and the stepper motor has lost steps. Another useful feature is the ability to set the current limit for the motor driver, as well as a separate hold current over the UART interface. This allows the system to reduce the current to a minimum when the motors are not moving during measurements, which reduces the radiated emission from the motors \cite{trinamic_motion_control_gmbh__co_kg_tc2209_2016},\cite{trinamic_motion_control_gmbh__co_kg_-015_2015}.

\subsection{Communication}
For communication, the positioning system primarily uses the SCPI (Standard Commands for Programmable Instruments) protocol, hosted over ethernet. The SCPI protocol was chosen, as it is a standardised protocol for programmable instruments and is widely used in the industry. This allows the positioning system to be easily integrated into existing test setups and automated test systems. The connection over ethernet was chosen due to the wide supply of affordable peripherals, from cables and switches to fibre optic converters, should these be required to prevent radiated emissions from the ethernet cable. Additionally, many test chambers will already be equipped with ethernet filters for outgoing connections. The ethernet interface also allows for a simple integration into existing test setups, as most modern computers and test equipment have an ethernet interface.

There is also a backup interface over USB, which is primarily used for configuring the device and for debugging. It is not very practical for use in a RF test chamber, as it would require running a USB cable out of the chamber to a computer, but it allows the user to easily reconfigure the network settings of the device, if the device is not reachable over the network.

For the implementation of the SCPI protocol, the VREKRER SCPI parser library was used \cite{chavez_vrekrervrekrer_scpi_parser_2025}. This allowed for a significant reduction in development time, as the library was able to handle most of the parsing and command handling, so that only a few features such as the error queue and the ethernet interface had to be implemented manually. 

\subsection{Power Supply}
The stepper motors are currently powered from a generic 12V DC power supply. Although the TMC2209 stepper motor drivers are rated for a maximum voltage of 29V, which would provide more torque at higher speeds, the lower voltage was chosen as it limits the rise and fall times of the current in the motor coils. This is desirable, as it reduces the slope, leading to reduced radiated harmonic emissions.

Currently, the ESP32 is powered from the onboard USB port, which is always connected to a computer during the development phase. For the final deployment this would be rather unpractical, so the onboard voltage regulator will be disabled by connecting the "Enable" pin on the ESP32 module to ground. This will allow the use of an external linear regulator to generate the required 3.3V from the 12V supply used for the stepper motors. For this application, a linear regulator is preferred over a switching regulator, as it eliminates a potential source of high frequency interference in the RF test chamber. 

Additionally, several bypass capacitors will be added to the power lines in accordance with the recommendations in the TMC2209 datasheet \cite{trinamic_motion_control_gmbh__co_kg_tc2209_2016}. These will help to ensure a reliable power supply for the stepper motor drivers. They have already been added to the schematic attached to this document.

\subsection{Firmware}
The firmware is written in the PlatformIO Framework and documented using Doxygen \cite{platformio_labs_platformio_nodate}, \cite{van_heesch_doxygen_nodate}. The firmware uses an object oriented approach, with individual classes for each of the core components of the system (stepper motors, SCPI, flash memory, etc.). The full firmware documentation can be found at \url{https://heinekamp.github.io/RF-Positioning-System/index.html}.

\newpage

\section{SCPI Interface}

\subsection{Getting Started}

The positioning system uses SCPI, which is a standardised command set for programmable instruments. SCPI was standardised in 1990 as an extension to the IEEE-488 standard (GPIB Bus). In contrast to the IEEE-488 standard, SCPI does not standardize the physical layer \cite{scpi_consortium_standard_1999}, \cite{noauthor_ieee_1987}. The positioning system accepts SCPI commands over its ethernet interface as well as via UART over the USB interface. It is fully standard compliant with regard to syntax, however not all of the required commands for full standard compliance were implemented due to the simple nature of the device. The following sections will describe how to connect to the device over both interfaces, as well as show a short example script for automating the device with python.

\subsubsection{Connecting over USB}

By default the positioning system is set up to receive serial commands in the following format, enabling compatibility to e.g. the Arduino IDE's Serial Monitor.
\begin{multicols}{2}
\begin{itemize}
    \itemsep0em 
    \item Baudrate: 9600
    \item Data Bits: 8
    \item Stop Bits: 1
    \item Parity: None
    \item Flow Control: None
    \item Termination Character: \texttt{\textbackslash n} (New line)
\end{itemize}
\end{multicols}

\begin{warningbox}
    PUTTY uses a carriage return (\texttt{\textbackslash r}) as the termination character. If you intend to use PUTTY to connect to the device via USB, you will need to change the termination character in the configuration file of the source code and recompile the firmware.
\end{warningbox}

\textbf{Using the Arduino IDE:}

\begin{enumerate}
    \item Install the Arduino IDE from https://www.arduino.cc/en/software/
    \item Connect the positioning system to your computer using the USB port on the ESP32
    \item Select the board from the drop down menu in the upper left 
    \item Open the serial monitor from Tools -> Serial Monitor
    \item Ensure the baud rate is set to 9600 (this should be the default value)
    \item Type *IDN? in the message field and send it using the enter key.
    \item If the positioning system returns a string along the lines of "EMES, RF-Positioning-System, V1.0.0, \#001", a successful serial connection has been established.
\end{enumerate}

\subsubsection{Connecting over Ethernet}
Upon boot, the positioning system will automatically assign itself a static IP address. The default value for this IP address is 192.168.0.55.

If a USB connection has been established, the current IP address may also be queried using the SYSTem:COMMunicate:ETHernet:ADDRess? command. An alternate IP address can also be set using the command SYSTem:COMMunicate:ETHernet:ADDRess <ip address>. Note that a reboot will be required for this change to take effect, a simple means to accomplish this is the *RST command.

A simple method to manually send commands over ethernet is to use the putty terminal emulator~\cite{simon_tatham_download_2025}. For an automated setup using a python script, see section \ref{sec:example_script}. The following steps will show how to connect to the positioning system over ethernet using putty:

\begin{enumerate}
    \item Install putty from \url{https://www.chiark.greenend.org.uk/~sgtatham/putty/latest.html}
    \item Open putty and select the "Raw" connection type under the other section on the session page.
    \item Enter the IP address of the positioning system in the "Host Name (or IP address)" field on the session page.
    \item Enter the port number in the "Port" field on the session page. The default port is 5025, which is the standard port for SCPI communication.
    \item For all other settings, the default values should be sufficient. Open the connection by clicking the "Open" button.
    \item Once the connection is established, you should see a blank terminal window. Type *IDN? in the terminal and press enter.
    \item If the positioning system returns a string along the lines of "EMES, RF-Positioning-System, V1.0.0, \#001", a successful ethernet connection has been established.
    
\end{enumerate}

\subsection{Example Script} \label{sec:example_script}
The following shows a simple example python script to connect to the positioning system over ethernet. It shows how to connect to the device, query the device ID, set some parameters, set some target positions and query the current position. The script uses the PyVISA library~\cite{pyvisa_authors_pyvisa_2025} to connect to the device.

\begin{lstlisting}[language=Python, caption={Example script to connect to the positioning system over ethernet or usb.}, label={lst:example_script}]

import pyvisa
import time

# Connect to the positioning system over Ethernet
rm = pyvisa.ResourceManager()
EthInstrument = rm.open_resource('TCPIP0::192.168.0.55::5025::SOCKET')
EthInstrument.write_termination = '\r\n'
EthInstrument.read_termination = '\n'

# Set a higher timeout, e.g., 10 seconds
EthInstrument.timeout = 10000  # Timeout in milliseconds

print(EthInstrument.query("*IDN?")) # Query and Print the IDN of the instrument

EthInstrument.write("CONFigure:MOTor:SPEED 5000") # Set the motor speed to 5000
EthInstrument.write("CONFigure:MOTor:ACCeleration 5000") # Set the motor acceleration to 5000

EthInstrument.write("CONTRol:ROTation:RELative2 360") # Rotate the motor 360 degrees

while (EthInstrument.query("*OPC?") != "1"):
        time.sleep(0.1) # Wait for the operation to complete

EthInstrument.write("CONFigure:MOTor:ACCeleration 1000") # Set the motor acceleration to 5000

for i in range(36):
    EthInstrument.write("CONTRol:ROTation:RELative2 10") # Rotate the motor 10 degrees
    print(EthInstrument.query("CONTRol:ROTation:ABSolute2?")) # Query the absolute position of the motor
    while (EthInstrument.query("*OPC?") != "1"):
        time.sleep(0.1) # Wait for the operation to complete
    time.sleep(1)

EthInstrument.write("CONFigure:MOTor:SPEED 20000") # Set the motor speed to 20000
EthInstrument.write("CONFigure:MOTor:ACCeleration 5000") # Set the motor acceleration to 5000
EthInstrument.write("CONTRol:ROTation:RELative2 360") # Rotate the motor 360 degrees

EthInstrument.write("CONTRol:ROTation:DIRection2 CCW") # Set the motor direction to counter-clockwise
EthInstrument.write("CONFigure:MOTor:SPEED 5000") # Set the motor speed to 5000
EthInstrument.write("CONTRol:ROTation:RELative2 360") # Rotate the motor 360 degrees

EthInstrument.write("CONTRol:ROTation:DIRection2 CW") # Set the motor direction to clockwise
EthInstrument.write("CONTRol:ROTation:RELative2 360") # Rotate the motor 360 degrees

for i in range(360):
    EthInstrument.write(f"CONTRol:ROTation:ABSolute2 {i}")
    print(EthInstrument.query("CONTRol:ROTation:ABSolute2?")) # Query the absolute position of the motor
    while (EthInstrument.query("*OPC?") != "1"):
        time.sleep(0.1) # Wait for the operation to complete

\end{lstlisting}

\newpage

\subsection{Command Reference} \label{sec:command_reference}

\subsubsection{Command Overview}

\begin{itemize}[label={}]
    \item \textbf{*IDN?}
    \vspace{-0.25em}
    \item \textbf{*RST}
    \vspace{-0.25em}
    \item \textbf{*OPC?}
    \vspace{-0.25em}
    \item \textbf{SYSTem}
    \vspace{-0.25em}
    \begin{itemize}[label={}]
        \item \texttt{:ERRor?}
        \item \texttt{:HELP:HEADers?}
        \item \texttt{:HELP:SYNTax?}
        \item \texttt{:VERSion?}
        \item \texttt{:DEBUG?}
        \item \texttt{:PRESet}
        \item \texttt{:COMMunicate:ETHernet}
        \begin{itemize}[label={}]
            \item \texttt{:PORT}
            \item \texttt{:PORT?}
            \item \texttt{:ADDRess}
            \item \texttt{:ADDRess?}
            \item \texttt{:MAC}
            \item \texttt{:MAC?}
            \item \texttt{:DGATeway?}
            \item \texttt{:RESET}
        \end{itemize}
    \end{itemize}
    \vspace{-0.25em}
    \item \textbf{CONTRol:ROTation}
    \vspace{-0.25em}
    \begin{itemize}[label={}]
        \item \texttt{:STEP\#}
        \item \texttt{:PERPetual\#}
        \item \texttt{:DIRection\#}
        \item \texttt{:DIRection\#?}
        \item \texttt{:RELative\#}
        \item \texttt{:ABSolute\#}
        \item \texttt{:ABSolute\#?}
    \end{itemize}
    \vspace{-0.25em}
    \item \textbf{CONFigure:MOTor}
    \vspace{-0.25em}
    \begin{itemize}[label={}]
        \item \texttt{:RMScurrent}
        \item \texttt{:RMScurrent?}
        \item \texttt{:HOLDcurrent}
        \item \texttt{:HOLDcurrent?}
        \item \texttt{:MICROsteps}
        \item \texttt{:MICROsteps?}
        \item \texttt{:SPEED}
        \item \texttt{:SPEED?}
        \item \texttt{:ACCELeration}
        \item \texttt{:ACCELeration?}
        \item \texttt{:STATus?}
    \end{itemize}
    \vspace{-0.25em}
    \item \textbf{DIAGnostic}
    \vspace{-0.25em}
    \begin{itemize}[label={}]
        \item \texttt{:SESSion:LIST?}
        \item \texttt{:SESSion:LOG?}
        \item \texttt{:SOCKet:LIST?}
        \item \texttt{:SYSTem?}
    \end{itemize}
\end{itemize}

\subsubsection{IEEE 488 Mandated Commands}
\textbf{*IDN?} \\
This command returns the device identification string. The string is formatted as follows: <manufacturer>, <model>, V<version>, \#<serial number>. For example, the device returns "EMES, RF-Positioning-System, V1.0.0, \#001".

\textbf{*RST} \\
This command initiates a full reboot on the controller. This will also reset the error queue and set the current position to 0° for both axes. \\
NOTE: This command does not reset the device configuration to its default values. For that please see SYSTem:PRESet.

\textbf{*OPC?} \\
This command returns 1 when all commands sent before this command have been executed. For example, this command can be used to ensure that the positioning system has reached the target position before any measurements are started.

\subsubsection{System Commands} \label{sec:system_commands}
\textbf{SYSTem:ERRor?} \\
This command returns the oldest error in the error queue. The error is returned as a string in the format "<error code>, <error message>". The error queue is a FIFO queue, meaning that the oldest error will be returned first. If there are no errors in the queue, this command will return "0, No Error". \\
NOTE: The error queue has a limited size. If the queue is full, new errors will be ignored and the SYSTem:ERRor? command will return "-350, "Queue overflow". After this the errors already in the queue can be read as normal, however the user should be aware that the most recent errors were not recorded.

\textbf{SYSTem:HELP:HEADers?} \\
This command returns a list of all available SCPI commands.

\textbf{SYSTem:HELP:SYNTax?} \\
This command returns detailed syntax help for a single command header, given as a parameter, e.g. \texttt{SYSTem:HELP:SYNTax? *IDN?}. The header must be given exactly as printed by \texttt{SYSTem:HELP:HEADers?} (matching is case-insensitive, and surrounding quotes are stripped if present). If the header is not recognized, the command returns "UNKNOWN" and queues an error.

\textbf{SYSTem:VERSion?} \\
This command returns the version of the firmware running on the positioning system.

\textbf{SYSTem:DEBUG?} \\
This command returns the debug information from the VREKRER SCPI parser library \cite{chavez_vrekrervrekrer_scpi_parser_2025}. This can be used to debug issues with the SCPI commands sent to the positioning system.

\textbf{SYSTem:PRESet} \\
This command resets the device configuration to the default values stored in the firmware. These can be adjusted by editing the configuration.h file in the source code.

\textbf{SYSTem:COMMunicate:ETHernet:PORT} \\
This command sets the port for the ethernet interface. The default value is 5025, which is the standard port for SCPI communication. \\
NOTE: A full reboot of the controller is required for this change to take effect. A simple means to accomplish this is the *RST command.

\textbf{SYSTem:COMMunicate:ETHernet:PORT?} \\
This command returns the current port for the ethernet interface.

\textbf{SYSTem:COMMunicate:ETHernet:ADDRess} \\
This command sets the IP address for the ethernet interface. The required format is SYSTem:COMMunicate:ETHernet:ADDRess XXX.XXX.XXX.XXX, where XXX is a integer value between 0 and 255. \\
NOTE: A full reboot of the controller is required for this change to take effect. A simple means to accomplish this is the *RST command.

\textbf{SYSTem:COMMunicate:ETHernet:ADDRess?} \\
This command returns the current IP address for the ethernet interface.

\textbf{SYSTem:COMMunicate:ETHernet:MAC} \\
This command sets the MAC address for the ethernet interface. The correct format would be SYSTem:COMMunicate:ETHernet:MAC XX:XX:XX:XX:XX:XX, where XX is a two digit hexadecimal number. \\
NOTE: A full reboot of the controller is required for this change to take effect. A simple means to accomplish this is the *RST command.

\textbf{SYSTem:COMMunicate:ETHernet:MAC?} \\
This command returns the current MAC address for the ethernet interface.

\textbf{SYSTem:COMMunicate:ETHernet:DGATeway?} \\
This command returns the configured default gateway for the ethernet interface as a dotted-quad IPv4 address. \\
NOTE: There is currently no corresponding setter command; the gateway is derived automatically and cannot be set directly over SCPI.

\textbf{SYSTem:COMMunicate:ETHernet:RESET} \\
This command resets the W5500 Ethernet module and re-initializes the network stack: it toggles the module's hardware reset pin, re-reads the IP and MAC address from flash, and restarts the SCPI listener. \\
NOTE: This drops all currently tracked SCPI sessions, including the one issuing this command.

\subsubsection{Rotation Control Commands}

The commands in the following section are used to control both rotation axes of the positioning system. The numeric suffix \# in the command names is used to indicate which axis the command applies to. For the azimuth axis the suffix should be set to 1, while for the elevation axis it should be set to 2. For example, the command to step the azimuth axis would be \texttt{CONTRol:ROTation:STEP1} and for the elevation axis it would be \texttt{CONTRol:ROTation:STEP2}.
\vspace{1em}

\textbf{CONTRol:ROTation:STEP\#} \\
This command jogs the specified axis exactly one full mechanical revolution at a fixed speed, with no acceleration ramp. It does not update the axis's tracked absolute position. This command is intended for testing and troubleshooting the motion system, not for normal operation.

\textbf{CONTRol:ROTation:PERPetual\#} \\
This command runs the specified axis continuously at a fixed speed. It does not return a response, and blocks all further command processing on both the Serial and Ethernet interfaces until the device is reset or power-cycled. \\
NOTE: This command is intended for testing and troubleshooting the motion system, not for normal operation.

\textbf{CONTRol:ROTation:DIRection\#} \\
This command sets the direction of rotation for the specified axis. The command takes a single argument, which can be either "CW" for clockwise or "CCW" for counter-clockwise. For example, to set the azimuth axis to rotate clockwise, the command would be \texttt{CONTRol:ROTation:DIRection1 CW}.

\textbf{CONTRol:ROTation:DIRection\#?} \\
This command returns the current direction of rotation for the specified axis. The return value will be either "CW" for clockwise or "CCW" for counter-clockwise.

\textbf{CONTRol:ROTation:RELative\#} \\
This command sets the target position for the specified axis relative to the current position. The command takes a single argument, which is the angle in degrees to move the axis. For example, to move the azimuth axis by 10 degrees, the command would be \texttt{CONTRol:ROTation:RELative1 10}.

\textbf{CONTRol:ROTation:ABSolute\#} \\
This command sets the target position for the specified axis as an absolute angle. The command takes a single argument, which is the angle in degrees to move the axis. For example, to move the azimuth axis to 90 degrees, the command would be \texttt{CONTRol:ROTation:ABSolute1 90}.

\textbf{CONTRol:ROTation:ABSolute\#?} \\
This command returns the current position of the specified axis in degrees as an absolute angle with respect to the zero position. The zero position is defined as the position when the system was last reset using the *RST command.

\subsubsection{Motor Configuration Commands}

The commands in the following section are used to configure the stepper motors used in the positioning system. They use the same numeric suffix system as the rotation control commands. In adition all of the parameters are live adjustable, meaning that the changes will take effect immediately without the need to reboot the controller.

\textbf{CONFigure:MOTor:RMScurrent} \\
This command sets the RMS current for the specified axis. The command takes a single argument, which is the current in milliamps. For example, to set the azimuth axis to \SI{1000}{\milli\ampere}, the command would be \texttt{CONFigure:MOTor:RMScurrent1 1000}.

\textbf{CONFigure:MOTor:RMScurrent?} \\
This command returns the current RMS current for the specified axis in milliamps.

\textbf{CONFigure:MOTor:HOLDcurrent} \\
This command sets the hold current for the specified axis. The command takes a single argument, which is a value between 0 and 32. The hold current will be set to a fraction over 32 of the RMS current set by the \texttt{CONFigure:MOTor:RMScurrent\#} command. For example, to set the azimuth axis to 50\% of the RMS current, the command would be \texttt{CONFigure:MOTor:HOLDcurrent1 16}.

\textbf{CONFigure:MOTor:HOLDcurrent?} \\
This command returns the current hold current for the specified axis as a value between 0 and 32. The hold current is represented by a fraction over 32 of the RMS current set by the \texttt{CONFigure:MOTor:RMScurrent\#} command.

\textbf{CONFigure:MOTor:MICROsteps} \\
This command sets the number of microsteps for the specified axis. Increasing this value will reduce in a better positioning accuracy, but comes at the cost of reducing the available torque. The command takes a single argument, which is the number of microsteps per step. The valid values are 1, 2, 4, 8, 16, 32, 64 and 128. For example, to set the azimuth axis to 16 microsteps per step, the command would be \texttt{CONFigure:MOTor:MICROsteps1 16}.

\textbf{CONFigure:MOTor:MICROsteps?} \\
This command returns the current number of microsteps set for the specified axis. 

\textbf{CONFigure:MOTor:SPEED} \\
This command sets the speed for the specified axis. The command takes a single argument, which is the speed in degrees per second. For example, to set the azimuth axis to 90 degrees per second, the command would be \texttt{CONFigure:MOTor:SPEED1 90}.

\textbf{CONFigure:MOTor:SPEED?} \\
This command returns the current speed set for the specified axis in degrees per second.

\textbf{CONFigure:MOTor:ACCELeration} \\
This command sets the acceleration for the specified axis. The command takes a single argument, which is the acceleration in degrees per second squared. For example, to set the azimuth axis to 10 degrees per second squared, the command would be \texttt{CONFigure:MOTor:ACCELeration1 10}.

\textbf{CONFigure:MOTor:ACCELeration?} \\
This command returns the current acceleration set for the specified axis in degrees per second squared.

\textbf{CONFigure:MOTor:STATus?} \\
This command returns the raw TMC2209 driver status registers for both axes, as two lines: "Motor 1 Status: <binary>" and "Motor 2 Status: <binary>". These are the raw DRV\_STATUS-style status bits from the driver IC, intended for diagnostic use.

\subsubsection{Diagnostic Commands}

The commands in this section are primarily intended for diagnosing communication issues, such as a client that is unable to establish or maintain a connection to the positioning system.

\textbf{DIAGnostic:SESSion:LIST?} \\
This command lists the currently active SCPI sessions over ethernet. It returns "\#SESSIONS <n>" followed by one CSV line per active session, giving its index, classification (SCPI/PING), TCP state, remote IP, remote port, local port, age, idle time, and received/transmitted byte counts.

\textbf{DIAGnostic:SESSion:LOG?} \\
This command lists recent SCPI session closures. It returns "\#CLOSES <n>" followed by one CSV line per closure (oldest first, up to the last 16), giving the time since it closed, the remote IP:port, the closure reason (EVICTED\_BY\_NEW/CLIENT\_FIN/RST/OTHER), session duration, idle time at close, and received/transmitted byte counts.

\textbf{DIAGnostic:SOCKet:LIST?} \\
This command returns the raw state of all 8 hardware sockets on the W5500 ethernet module, as "\#SOCKETS 8" followed by one CSV line per socket, giving its index, TCP state, and whether it is currently tracked as a SCPI session.

\textbf{DIAGnostic:SYSTem?} \\
This command returns system and reset health diagnostics as comma-separated key=value pairs: uptime in seconds, free heap, minimum free heap seen, the reason for the last reset, the boot count, the number of ethernet link flaps, and the number of ethernet re-initializations.

\subsubsection{Error Codes}
In compliance with the SCPI standard, the positioning system implements an error queue. This will return a error code along with a message for any error that has occurred. As described in Section \ref{sec:system_commands}, the error queue can be queried using the command \texttt{SYSTem:ERRor?}. The error queue is a FIFO queue, meaning that the oldest error will be returned first. An overview of the implemented error codes is shown in Table \ref{tab:error_codes}.

\begin{table}[h!]
\centering
\begin{tabularx}{\textwidth}{|c|X|}
\hline
\textbf{Error Code} & \textbf{Description} \\ \hline
0 & No Error \\ \hline
-350 & Queue overflow \\ \hline
131 & Invalid Suffix \\ \hline
220 & Invalid parameter value \\ \hline
224 & Illegal parameter value \\ \hline
\end{tabularx}
\caption{Error Codes and Descriptions}
\label{tab:error_codes}
\end{table}

\newpage

\section{Service}
\subsection{Maintenance}

\subsubsection{Belt Tension}

For checking the belt tension, the Gates Carbon Drive app \cite{gates_tools_nodate} will be used. It uses the devices microphone to measure the resonant frequency of the belt when plucked. The target frequencies were calculated based on the type and length of the belt and are noted in the corresponding assembly steps below \cite{zoltan_benchtop_2019}. 

\assemblystep{1 Motor Belts}{../assets/assembly/1-belt-tension.png}{\hexkey{2.5mm} \smartphone{}}{
  \begin{itemize}[left=0pt, labelsep=4pt, itemsep=0pt]
    \partitem{part1}{Loosen the four M3x8 screws on each motor using a 2.5mm hex key.}
    \partitem{part2}{Move the motor back and forth to adjust the belt tension. }
    \partitem{part3}{Retighten the screws once the correct belt tenstion is set.}
  \end{itemize}
  \vspace{-1em}
  \begin{notebox}
    The upper belt should be tensioned to \SI{190}{\Hz} and the lower belt to \SI{228}{\Hz}~\cite{zoltan_benchtop_2019}.\\
  \end{notebox}
}
\enlargethispage{2\baselineskip}
\vspace{-\baselineskip}

\assemblystep{2 Top Belt}{../assets/assembly/2-top-belt-tension.png}{\hexkey{2.0mm} \smartphone{}}{
  \begin{itemize}[left=0pt, labelsep=4pt, itemsep=0pt]
    \partitem{part1}{Loosen the M4x5  grub screw using a 2.0mm hex key.}
    \partitem{part2}{Move the bearing holder up and down to adjust the belt tension. }
    \partitem{part3}{Optionally this grub screw can also be loosend to move the entire shaft}
    \partitem{part4}{Retighten the screws once the correct belt tenstion is set.}
  \end{itemize}
  \vspace{-1em}
  \begin{notebox}
    The belt should be tensioned to \SI{159}{\Hz}~\cite{zoltan_benchtop_2019}.
  \end{notebox}
}

\subsection{Component Replacement}

The following section describes how to disassemble the positioning system in order to replace components. To reassemble the system, the steps should be followed in reverse order.

\subsubsection{Stepper Motors}

\assemblystep{1 Stepper Motor}{../assets/assembly/1-remove-motor.png}{\hexkey{2.5mm} }{
    \begin{itemize}[left=0pt, labelsep=4pt, itemsep=0pt]
        \partitem{part1}{Remove the four M3x8 (HW~10) screws on each motor using a 2.5mm hex key.}
        \partitem{part2}{Move the motor towards the main tower to free it from the timing belt.}
      \end{itemize}
}

\assemblystep{2 Timing Pulley \& Wire}{../assets/assembly/2-pulley-wire.png}{\hexkey{2.0mm} }{
  \begin{itemize}[left=0pt, labelsep=4pt, itemsep=0pt]
    \partitem{part1}{Remove the two M4x5 grub screws (HW~9) on each pulley using a 2.0mm hex key.}
    \partitem{part2}{Pull the timing pulley (HW~15) of the shaft.}
    \partitem{part3}{Remove the wire from the motor.}
  \end{itemize}
  \begin{warningbox}
    When reinstalling the timing pulley, ensure that one grub screw is aligned with the flat side of the motor shaft.\\
  \end{warningbox}
}

\assemblystep{3 Motor Mount}{../assets/assembly/3-motor-mount.png}{\torx{T10} }{
  \begin{itemize}[left=0pt, labelsep=4pt, itemsep=0pt]
    \partitem{part1}{Remove the six 3x30mm universal screws (HW~13) using a T10 torx screwdriver. The motor mount can now be removed from the base plate.}
    
  \end{itemize}
}

\subsubsection{Upper mast}
\assemblystep{1 Timing Belt}{../assets/assembly/1-timing-belt.png}{\hexkey{2.0mm} }{
  \begin{itemize}[left=0pt, labelsep=4pt, itemsep=0pt]
    \partitem{part1}{Remove the two M4x5 grub screws (HW~9) using a 2.0mm hex key.}
    \partitem{part2}{Push the bearing holder down towards the shaft and the shaft down into the head unit to relieve the tension on the timing belt.}
    \partitem{part3}{The timing belt (HW~18) can now be removed.}
  \end{itemize}
}

\assemblystep{2 Upper Axle}{../assets/assembly/2-upper-axle.png}{\hexkey{2.0mm} }{
  \begin{itemize}[left=0pt, labelsep=4pt, itemsep=0pt]
    \partitem{part1}{Remove the three M4x5 grub screws (HW~9) from the locking rings and the timing puley using a 2.0mm hex key.}
    \partitem{part2}{The axle (SHAFT4) can now be slid out of the bearing holder, releasing the timing pulley (3D~8) and the locking rings (3D~5).}
  \end{itemize}
  \begin{warningbox}
    When reinstalling the axle, ensure that the timing pulley is aligned with the flat side of the axle.
  \end{warningbox}
}

\assemblystep{3 Bearing Holder \& Shaft}{../assets/assembly/3-bearing-holder-shaft.png}{}{
  \begin{itemize}[left=0pt, labelsep=4pt, itemsep=0pt]
    \partitem{part1}{As the grub screws were already removed in step 1, the bearing holder (3D~7) can now be pulled off the shaft.}
    \partitem{part2}{Following this, the shaft (SHAFT3) can be pulled out of the head unit.}

  \end{itemize}
}

\assemblystep{4 Bearings}{../assets/assembly/4-bearings.png}{\flathead{}}{
  \begin{itemize}[left=0pt, labelsep=4pt, itemsep=0pt]
    \partitem{part1}{Finally, the bearings (HW~3) can be pulled out of the bearing holder. The easiest way to do this is to carefully use a small flathead screwdriver to pry them out.}
  \end{itemize}
  \begin{notebox}
    If the bearings come apart during removal, they can be reassembled by reinserting the bearing balls into the outer ring and then pressing the inner ring back in.
  \end{notebox}
}

\subsubsection{Head Unit}
\assemblystep{1 Lower Head Alignment}{../assets/assembly/1-aligment-ring.png}{\flathead{}}{
  \begin{itemize}[left=0pt, labelsep=4pt, itemsep=0pt]
    \partitem{part1}{Unscrew the four M3x20 screws (HW~7) holding the head alignment ring (3D~4) in place.}
    \partitem{part2}{Lower the head alignment ring until it sits on the mounting screws for the shaft stabilizer.}
  \end{itemize}
  \begin{notebox}
    These screws must only be unscrewed far enough to allow the head alignment ring to be lowered. This way they will still hold the nuts on the inside of the alignment ring in place.
  \end{notebox}
}
\assemblystep{2 Head Bottom Plate}{../assets/assembly/2-head-bottom.png}{\flathead{}}{
  \vspace{-1.5em}
  \begin{itemize}[left=0pt, labelsep=4pt, itemsep=0pt]
    \partitem{part1}{Remove the 10 M3x20 screws (HW~7) holding the head bottom plate (3D~2) in place.}
    \partitem{part2}{Lower the head bottom plate until it sits on the head alignment ring.}
  \end{itemize}
  \vspace{-2.2em}
  \begin{warningbox}
    There are 70 loose bearing balls (HW~4), which sit in a groove ontop of the head bottom plate. It is recommended to unscrew the screws evenly to ensure the plate stays perpendicular to the shaft. Once the plate is lowered far enough, the bearing balls can be carefully removed.
  \end{warningbox}
}
\assemblystep{3 Head Top Assembly}{../assets/assembly/3-head-top.png}{}{
  \vspace{-1.5em}
  \begin{itemize}[left=0pt, labelsep=4pt, itemsep=0pt]
    \partitem{part1}{At this point the remaining top assembly can be pulled up and off the positioning system.}
  \end{itemize}
  \vspace{-1em}
  \begin{warningbox}
    Once again, this will expose 70 loose bearing balls (HW~4), which sit under the top asseembly.
  \end{warningbox}
  \begin{notebox}
    During reassembly this is a good point to verify that the bevel gears are engaging correctly. 
  \end{notebox}
}

\assemblystep{4 Nuts}{../assets/assembly/6-top-nuts.png}{\hexkey{2.5mm}}{
  \begin{itemize}[left=0pt, labelsep=4pt, itemsep=0pt]
    \partitem{part1}{Remove the 20 M3 nuts (HW~11) from the pockets in the head unit.}
  \end{itemize}
    \begin{notebox}
        One of the previously removed M3x20 screws can be used to push the nuts out of the pockets. During reassembly, the nuts can be pulled back into the pockets by sticking the screws though the hole and threading the nuts onto the tip of the screw.
    \end{notebox}
}

\assemblystep{5 Shaft}{../assets/assembly/4-top-shaft.png}{\hexkey{2.0mm}}{
  \vspace{-1.5em}
  \begin{itemize}[left=0pt, labelsep=4pt, itemsep=0pt]
    \partitem{part1}{Remove the two M4x5 grub screws (HW~9) from the locking ring (3D~6) and the bevel gear (HW~1) using a 2.0mm hex key.}
    \partitem{part2}{The shaft (SHAFT3) can now be pulled out of the head unit, thereby releasing the locking ring and the bevel gear.}
    \partitem{part3}{Remove the last grub screw (HW~9) to release the timing pulley (3D~9) from the shaft.}
  \end{itemize}
  \vspace{-1em}
}

\assemblystep{6 Bearings}{../assets/assembly/5-bearings.png}{\flathead{}}{
  \vspace{-1.5em}
  \begin{itemize}[left=0pt, labelsep=4pt, itemsep=0pt]
    \partitem{part1}{Remove the three bearings (HW~2) from the head unit. The easiest way to do this is to carefully use a small flathead screwdriver to pry them out.}
  \end{itemize}
    \begin{notebox}
        If the bearings come apart during removal, they can be reassembled by reinserting the bearing balls into the outer ring and then pressing the inner ring back in.
    \end{notebox}
  \vspace{-1em}
}

\subsubsection{Head Base}
\assemblystep{1 Gears}{../assets/assembly/1-gears.png}{\hexkey{2.0mm}}{
  \begin{itemize}[left=0pt, labelsep=4pt, itemsep=0pt]
    \partitem{part1}{Remove the two M4x5 grub screws (HW~9) from the gears using a 2.0mm hex key.}
    \partitem{part2}{The bevel gear (HW~1) and spur gear (3D~10) can now be pulled off the shaft.}
  \end{itemize}
  \begin{notebox}
    During reassembly, ensure that the grub screws are aligned with the flat side of the shaft.
    
    The bevel gear should be mounted \SI{8}{\milli\meter} above the bearing.
  \end{notebox}
}

\assemblystep{2 Head Base}{../assets/assembly/2-top-base.png}{\hexkey{2.5mm}}{
  \begin{itemize}[left=0pt, labelsep=4pt, itemsep=0pt]
    \partitem{part1}{Remove the four M3x20mm screws (HW~7) from the head base using a 2.5mm hex key.}
    \partitem{part2}{The head base assembly (3D~3) cam now be pulled off the top of the mast.}
  \end{itemize}
}

\assemblystep{3 Nuts}{../assets/assembly/3-top-nuts.png}{}{
  \begin{itemize}[left=0pt, labelsep=4pt, itemsep=0pt]
    \partitem{part1}{Remove the 8 M3 nuts (HW~11) from the pockets in the head base.}
  \end{itemize}
}

\assemblystep{4 Bearings}{../assets/assembly/4-top-bearings.png}{\flathead{}}{
  \begin{itemize}[left=0pt, labelsep=4pt, itemsep=0pt]
    \partitem{part1}{Remove the two bearings (HW~2) from the head base. The easiest way to do this is to carefully use a small flathead screwdriver to pry them out.}
  \end{itemize}
  \begin{notebox}
    If the bearings come apart during removal, they can be reassembled by reinserting the bearing balls into the outer ring and then pressing the inner ring back in.
  \end{notebox}
}

\assemblystep{5 Alignment Ring}{../assets/assembly/5-alignment-ring.png}{\hexkey{2.5mm}}{
  \begin{itemize}[left=0pt, labelsep=4pt, itemsep=0pt]
    \partitem{part1}{Now that the head base is removed, the head alignment ring (3D~4) can be pulled off the top of the mast.}
    \partitem{part2}{Once it is removed, there are eight M3 nuts (HW~11) on the inside of the screw holes, which can be removed as described in step 3.}
  \end{itemize}
}

\subsubsection{Base Assembly}
\assemblystep{1 Mast}{../assets/assembly/1-base-mast.png}{\hexkey{2.5mm}}{
  \begin{itemize}[left=0pt, labelsep=4pt, itemsep=0pt]
    \partitem{part1}{Remove the four M3x20mm screws (HW~8) that are securing the mast to the base using a 2.5mm hex key.}
    \partitem{part2}{At this point the mast can be pulled out of the base assembly.}
  \end{itemize}
}

\assemblystep{2 Base Screws}{../assets/assembly/2-base-screws.png}{\torx{T10}}{
  \begin{itemize}[left=0pt, labelsep=4pt, itemsep=0pt]
    \partitem{part1}{Remove the eight 3x30mm universal screws (HW~13) that are securing the pipe mount (3D~14) to the base plate.}
    \partitem{part2}{The pipe mount can now be removed from the base plate.}
  \end{itemize}
}

\assemblystep{3 Bearings \& Nuts}{../assets/assembly/3-pipe-mount.png}{\flathead{}}{
  \begin{itemize}[left=0pt, labelsep=4pt, itemsep=0pt]
    \partitem{part1}{Remove the eight M3 nuts (HW~12) from the pipe mount (3D~14). These nuts are located in the pockets on the inside of the pipe mount.}
    \partitem{part2}{Remove the two bearings (HW~2) from the pipe mount. The easiest way to do this is to carefully use a small flathead screwdriver to pry them out.}
  \end{itemize}
}

\subsubsection{Mast}

\assemblystep{1 Shafts}{../assets/assembly/1-shafts.png}{}{
  \begin{itemize}[left=0pt, labelsep=4pt, itemsep=0pt]
    \partitem{part1}{Pull the two shafts (SHAFT1 and SHAFT2) out of the bottom of the mast.}
  \end{itemize}
}

\assemblystep{2 Stabilizer Screws}{../assets/assembly/2-stabilizer-screws.png}{\hexkey{2.5mm}}{
  \begin{itemize}[left=0pt, labelsep=4pt, itemsep=0pt]
    \partitem{part1}{Remove the six M3x20mm screws (HW~7) that are securing the shaft stabilizers (3D~12) to the mast using a 2.5mm hex key.}
  \end{itemize}
}

\assemblystep{3 Stabilizers}{../assets/assembly/3-stabilizers.png}{}{
  \begin{itemize}[left=0pt, labelsep=4pt, itemsep=0pt]
    \partitem{part1}{The shaft stabilizers (3D~12) can now be pulled out of the mast.}
  \end{itemize}
}

\assemblystep{4 Stablizer lids}{../assets/assembly/4-stabilizer-lid.png}{\hexkey{2.5mm}}{
  \begin{itemize}[left=0pt, labelsep=4pt, itemsep=0pt]
    \partitem{part1}{Remove the four M3x20mm screws (HW~7) that are securing the stabilizer lids (3D~11) to the stabilizers (3D~12) using a 2.5mm hex key.}
    \partitem{part2}{The stabilizer lids can now be removed from the stabilizers.}
  \end{itemize}
}

\assemblystep{5 Stabiliyer bearings}{../assets/assembly/5-stabilizer-bearings.png}{\flathead{}}{
  \begin{itemize}[left=0pt, labelsep=4pt, itemsep=0pt]
    \partitem{part1}{Remove the two bearings (HW~2) from each stabilizer (3D~12). The easiest way to do this is to carefully use a small flathead screwdriver to pry them out.}
  \end{itemize}
  \begin{notebox}
    If the bearings come apart during removal, they can be reassembled by reinserting the bearing balls into the outer ring and then pressing the inner ring back in.
  \end{notebox}
}

\newpage
\section{Further Work}

The controller is now implemented on a dedicated PCB (see the schematics in the Appendix), which powers the ESP32 from the same supply as the stepper motors and adds filtering on the power and signal lines to reduce radiated emissions, in place of the earlier breadboard prototype. Radiated emissions testing has also been carried out with a shielding enclosure around the base assembly, which measurably reduced emissions compared to the unshielded configuration. Formalizing this into a permanent, CAD-documented enclosure (rather than the enclosure used for testing) remains further work.

Further practical use may uncover potential improvements to the SCPI command set. For example, it may be useful to expose further configuration options, or add the ability to reset the zero position without having to reboot the controller. Additionally, there are some instances where the commands could be implemented in a more intuitive manner. For example, currently for controlling the rotation axes the suffix to select the axis is added at the very end of the command, e.g. \texttt{CONTRol:ROTation:RELative1}, a more intuitive option may be \texttt{CONTRol:ROTation1:RELative}, to signify a relative rotation on rotation axis 1.

\newpage

\appendix
\newpage
\section{Replaceable Parts}

\subsection{Controller}

\begin{tabularx}{\textwidth}{|C|c|X|c|C|}
    \hline
    \textbf{Component} \textbf{Designator}& \textbf{Qty} & \textbf{Description} & \textbf{Manufacturer} & \textbf{Manufacturer} \textbf{Part Nr.} \\
    \hline
    A1 & 1 & ESP32 Microcontroller & Adafruit Industries & 54300\\
    \text{[A1]} & 1 & FeatherWing Ethernet & Adafruit Industries & 3201 \\
    U1 - U2 & 2 & Stepstick based around the Trinamic 2209 driver IC & BIGTREETECH & TMC2209 V1.3\\
    C1, C10 & 2 & 2200 uF Capacitor & Würth Elektronik & 860010580021 \\
    C4, C7, C11 & 3 & 1000 uF Capacitor & Würth Elektronik & 860040578014 \\
    C9, C15, C16 & 3 & 10 uF Capacitor & Würth Elektronik & 885012214006 \\
    C8 & 1 & 1 uF Capacitor & Würth Elektronik & 885012209069 \\
    C2, C3, C5, C6, C13, C19 & 6 & 100 nF Capacitor & Generic & -- \\
    C12, C17, C20 & 3 & 100 uF Capacitor & Generic & -- \\
    C14, C18 & 2 & 10 nF Capacitor & Generic & -- \\
    C21 & 1 & 1 nF Capacitor & Generic & -- \\
    C22 - C29 & 8 & 2.2 nF Capacitor & Generic & -- \\
    \hline
\end{tabularx}

\subsection{3D-Printed Parts}

\begin{tabularx}{\textwidth}{|C|c|X|c|}
    \hline
    \textbf{Component} \textbf{Designator}& \textbf{Qty} & \textbf{Description} & \textbf{Material} \\
    \hline
    3D 1 & 1 & Head Top Piece & PLA \\
    3D 2 & 1 & Head Bottom Piece & PLA \\
    3D 3 & 1 &  Head Base & PLA \\
    3D 4 & 1 &  Head Alignment Ring & PLA \\
    3D 5 & 2 &  \SI{5}{mm} Locking Ring & PLA \\
    3D 6 & 1 &  \SI{8}{mm} Locking Ring & PLA \\
    3D 7 & 1 &  Bearing Holder & PLA \\
    3D 8 & 1 &  GT2 Timing Pulley, 20 Teeth, \SI{5}{mm} Bore & PLA \\
    3D 9 & 1 &  GT2 Timing Pulley, 20 Teeth, \SI{8}{mm} Bore & PLA \\
    3D 10 & 1 & Spur Gear, 24 Teeth, \SI{8}{mm} Bore & PLA \\
    3D 11 & 2 & Shaft Stabilizer Lid & PLA \\
    3D 12 & 2 & Shaft Stabilizer Base & PLA \\
    3D 13 & 1 & Motor Mount & PA6-CF15 \\
    3D 14 & 1 & Pipe Mount & PA6-CF15 \\
    \hline
\end{tabularx}

\newpage

\subsection{Mechanical Parts}

\begin{tabularx}{\textwidth}{|C|c|X|C|C|}
    \hline
    \textbf{Component} \textbf{Designator}& \textbf{Qty} & \textbf{Description} & \textbf{Manufacturer} & \textbf{Manufacturer} \textbf{Part Nr.} \\
    \hline
    \endhead
    PIPE & 1 & PVC Pipe 100\ x\ 104\ x\ 1000\ mm & OBI Group Sourcing GmbH & 4007873971266\\
    SHAFT1-3 & 2 & GFRP Shaft, \SI{8}{mm} Diameter, \SI{2000}{mm} Length & CG TEC GmbH & 008000-e-2000 \\
    SHAFT4 & 1 & GFRP Shaft, \SI{5}{mm} Diameter, \SI{1000}{mm} Length & CG TEC GmbH & 005000-e \\ 
    HW 1 & 2 & Bevel Gear, 1.5 Module, 16 Teeth, \SI{8}{mm} Bore& igus GmbH & S270GM-BG-150-016-00-080-R-10 \\
    HW 2 & 11 & Deep Groove Ball Bearing, 8\ x\ 22\ x\ 7\ mm & igus GmbH & BB-608-B180-30-GL \\
    HW 3 & 2 & Deep Groove Ball Bearing, 5\ x\ 11\ x\ 5\ mm & igus GmbH & BB-685-B180-30-GL \\
    HW 4 & 140 & POM Bearing Balls, 6mm & Generic & - \\
    HW 5 & 1 & GT2 Timing Pulley, 40 Teeth, \SI{8}{mm} Bore & Misumi & GPA40GT2060-B-P8 \\
    HW 6 & 1 & GT2 Timing Pulley, 20 Teeth, \SI{8}{mm} Bore & CR3D & PU-20-2GT-B8-06-SIL \\
    HW 6.5 & 2 & GT2 Timing Pulley, 20 Teeth, \SI{5}{mm} Bore & CR3D & PU-20-2GT-B5-06-SIL \\
    HW 7 & 30 & DIN912 M3x20 Machine Screw PA6.6 & Würth & 02783  20 \\
    HW 8 & 4 & DIN912 M3x20 Machine Screw 12.9 Steel & Würth & 00833 20\\
    HW 9 & 4 & DIN913 M4x5 Grub Screw 45H Steel & Würth & 02554 5\\
    HW 10 & 4 & DIN912 M3x8 Machine Screw 12.9 Steel & Würth & 00833 8\\
    HW 11 & 60 & DIN934 M3 Nut PA6.6 & Würth & 03233\\
    HW 12 & 2 & DIN934 M3 Nut 12.9 & Würth & 03103\\
    HW 13 & 10 & Universal screw 3x30mm & SPAX & 1197000300303\\
    HW 14 & 10 & Expansion Dowel 4x20mm & Fischer & 567820\\
    HW 15 & 1 & GT2 Timing Pulley, 20 Teeth, \SI{5}{mm} Bore & CR3D & PU-20-2GT-B5-06-SIL \\
    HW 16 & 2 & NEMA 17 Stepper Motor, 1.8°/step, \SI{0.54}{\newton\meter} & LDO Motors & LDO-42STH48-2504AC\\
    HW 17 & 1 & GT2 Timing Belt, 6x250\ mm & Gates & 9400-54082\\
    HW 18 & 1 & GT2 Timing Belt, 6x300\ mm & Gates & 9400-54088\\
    HW 19 & 1 & GT2 Timing Belt, 6x350\ mm & Gates & 9400-54097 \\
    \hline
\end{tabularx}

\section{Schematics}
\includepdf[pages=-, landscape=true]{../Drawings/Controller-Schematic.pdf}
\includepdf[pages=-]{../Drawings/Mechanical-Schematic.pdf}

\section{Default values}

The following section lists the default values for the configuration parameters of the positioning system. The last column indicates whether these can be adjusted by sending the appropriate SCPI commands, as described in Section \ref{sec:command_reference}. These values are all stored in flash memory and will persist after a reboot, they can be restored by sending the \texttt{SYSTem:PRESet} command. To adjust the other parameters, modifications to the configuration file in the source code are required. 

\begin{table}[h!]
  \centering
  \begin{tabularx}{\textwidth}{|C|C|X|C|}
  \hline
  \textbf{Parameter Name} & \textbf{Default Value} & \textbf{Description} & \textbf{Configurable over SCPI} \\ \hline
  SCPI-PORT               & 5025                   & Port number for SCPI communication. & Yes \\ \hline
  IP-ADDRESS              & 192.168.0.55           & IP address for the Ethernet interface. & Yes \\ \hline
  MAC-ADDRESS             & \{0xDE, 0xAD, 0xBE, 0xEF, 0xFE, 0xED\} & MAC address for the Ethernet interface. & Yes \\ \hline
  STEPS-PER-REV           & 200                    & Number of steps per revolution for the stepper motors. & No \\ \hline
  MOTOR1-STEP-PIN         & 15                     & GPIO pin for the step signal of motor 1. & No \\ \hline
  MOTOR2-STEP-PIN         & 13                     & GPIO pin for the step signal of motor 2. & No \\ \hline
  R-SENSE                 & 0.11                   & Sense resistor value for the stepper motor drivers. & No \\ \hline
  STEP-DELAY              & 4                      & Delay between steps in milliseconds. & No \\ \hline
  RMS-CURRENT             & 1600                  & RMS current for the stepper motors in milliamps. & Yes \\ \hline
  HOLD-CURRENT            & 8                      & Hold current as a fraction (1/32) of RMS current. & Yes \\ \hline
  MICROSTEPS              & 16                     & Number of microsteps per step for the stepper motors. & Yes \\ \hline
  STEPPER1-ADDRESS        & 0                      & UART address for stepper motor 1. & No \\ \hline
  STEPPER2-ADDRESS        & 1                      & UART address for stepper motor 2. & No \\ \hline
  AXIS1-GEAR-RATIO        & 1                      & Gear ratio for axis 1. & No \\ \hline
  AXIS2-GEAR-RATIO        & 6                      & Gear ratio for axis 2. & No \\ \hline
  SPEED                   & 1000                   & Default speed for the stepper motors in steps per second. & Yes \\ \hline
  ACCELE-RATION            & 5000                   & Default acceleration for the stepper motors in steps per second squared. & Yes \\ \hline
  \end{tabularx}
  \caption{Configuration Parameters and SCPI Update Availability}
  \label{tab:config_parameters}
  \end{table}

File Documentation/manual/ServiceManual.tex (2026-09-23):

\documentclass[11pt,a4paper]{article}

% Packages und Einstellungen
\input{Inhalte/Praeambel}

\begin{document}

    %%%%%%%%%%%%%%%%%%%%%%%%%%%%%%%%%%%%%%%%%%%%%%%%%%%%%%%%%%%%%%%%%%%%%%%%%%%%%%%%%%%
    %% Formale Kriterien
    %%%%%%%%%%%%%%%%%%%%%%%%%%%%%%%%%%%%%%%%%%%%%%%%%%%%%%%%%%%%%%%%%%%%%%%%%%%%%%%%%%%
    %\input{Inhalte/Formalia}                                                         \clearpage

    %%%%%%%%%%%%%%%%%%%%%%%%%%%%%%%%%%%%%%%%%%%%%%%%%%%%%%%%%%%%%%%%%%%%%%%%%%%%%%%%%%%
    %% Deckblätter zur Auswahl
    %%%%%%%%%%%%%%%%%%%%%%%%%%%%%%%%%%%%%%%%%%%%%%%%%%%%%%%%%%%%%%%%%%%%%%%%%%%%%%%%%%%
    \input{Deckblätter/Messtechnik}                                          \clearpage

    %%%%%%%%%%%%%%%%%%%%%%%%%%%%%%%%%%%%%%%%%%%%%%%%%%%%%%%%%%%%%%%%%%%%%%%%%%%%%%%%%%%
    %% Inhaltsverzeichnis
    %%%%%%%%%%%%%%%%%%%%%%%%%%%%%%%%%%%%%%%%%%%%%%%%%%%%%%%%%%%%%%%%%%%%%%%%%%%%%%%%%%%
    \pagenumbering{Roman}
    \tableofcontents                                                         \clearpage

    %%%%%%%%%%%%%%%%%%%%%%%%%%%%%%%%%%%%%%%%%%%%%%%%%%%%%%%%%%%%%%%%%%%%%%%%%%%%%%%%%%%
    %% Beginn des Hauptteils
    %%%%%%%%%%%%%%%%%%%%%%%%%%%%%%%%%%%%%%%%%%%%%%%%%%%%%%%%%%%%%%%%%%%%%%%%%%%%%%%%%%%
    \pagenumbering{arabic}
    
    % Minimalbeispiel
    %\input{Inhalte/Minimalbeispiel}                                                  \clearpage

    % Eure Inhalte
    \input{Inhalte/Protokoll}                                                           \clearpage

    %%%%%%%%%%%%%%%%%%%%%%%%%%%%%%%%%%%%%%%%%%%%%%%%%%%%%%%%%%%%%%%%%%%%%%%%%%%%%%%%%%%
    %% Literaturverzeichnis
    %%%%%%%%%%%%%%%%%%%%%%%%%%%%%%%%%%%%%%%%%%%%%%%%%%%%%%%%%%%%%%%%%%%%%%%%%%%%%%%%%%%
    \printbibliography                                                       \clearpage

	%%%%%%%%%%%%%%%%%%%%%%%%%%%%%%%%%%%%%%%%%%%%%%%%%%%%%%%%%%%%%%%%%%%%%%%%%%%%%%%%%%%
	%% Anhang
	%%%%%%%%%%%%%%%%%%%%%%%%%%%%%%%%%%%%%%%%%%%%%%%%%%%%%%%%%%%%%%%%%%%%%%%%%%%%%%%%%%%
	%\input{Inhalte/Appendix}                                                           \clearpage
\end{document}

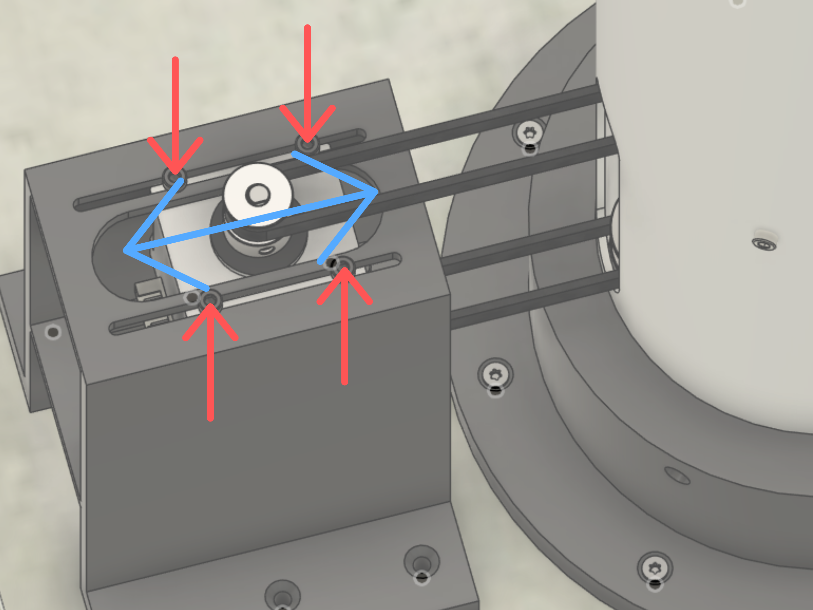
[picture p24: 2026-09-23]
Documentation/assets/assembly/1-belt-tension.png

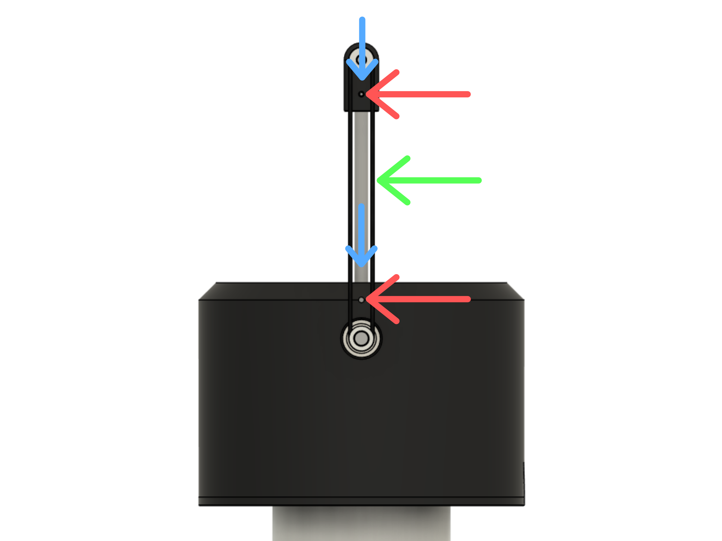
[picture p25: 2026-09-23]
Documentation/assets/assembly/1-timing-belt.png

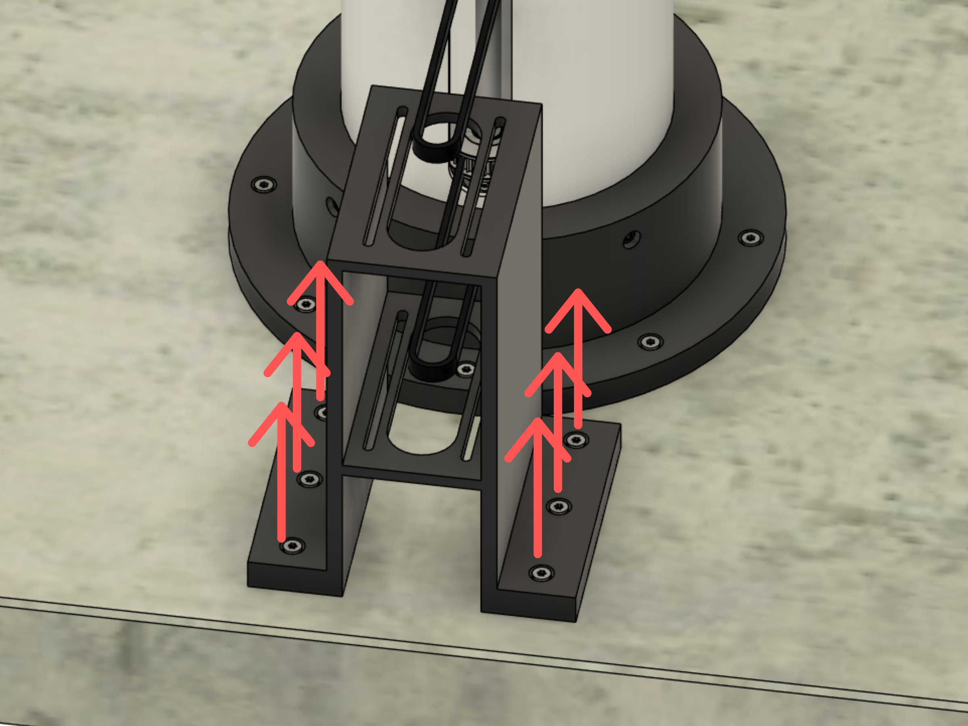
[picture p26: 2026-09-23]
Documentation/assets/assembly/3-motor-mount.png

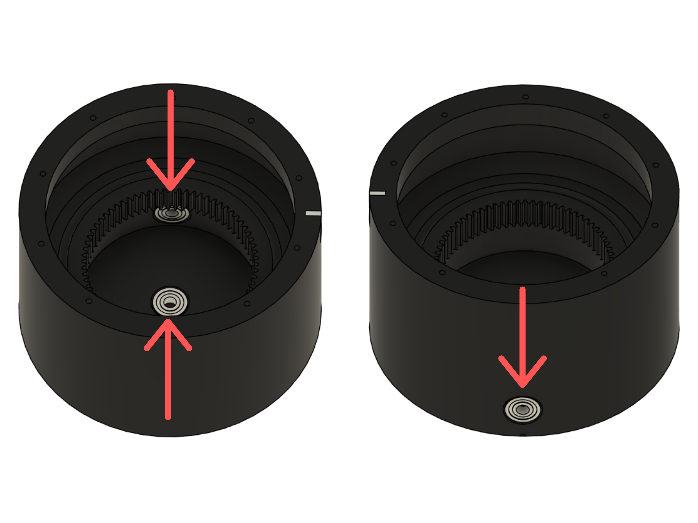
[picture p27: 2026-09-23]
Documentation/assets/assembly/5-bearings.png

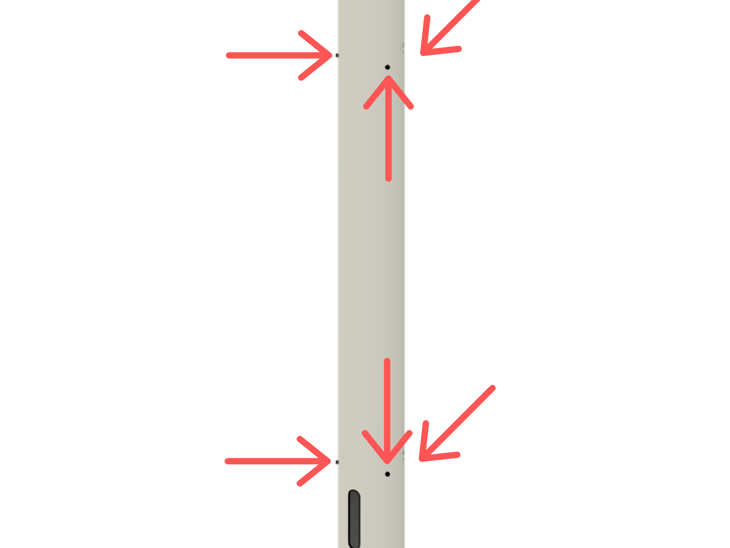
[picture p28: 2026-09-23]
Documentation/assets/assembly/2-stabilizer-screws.png

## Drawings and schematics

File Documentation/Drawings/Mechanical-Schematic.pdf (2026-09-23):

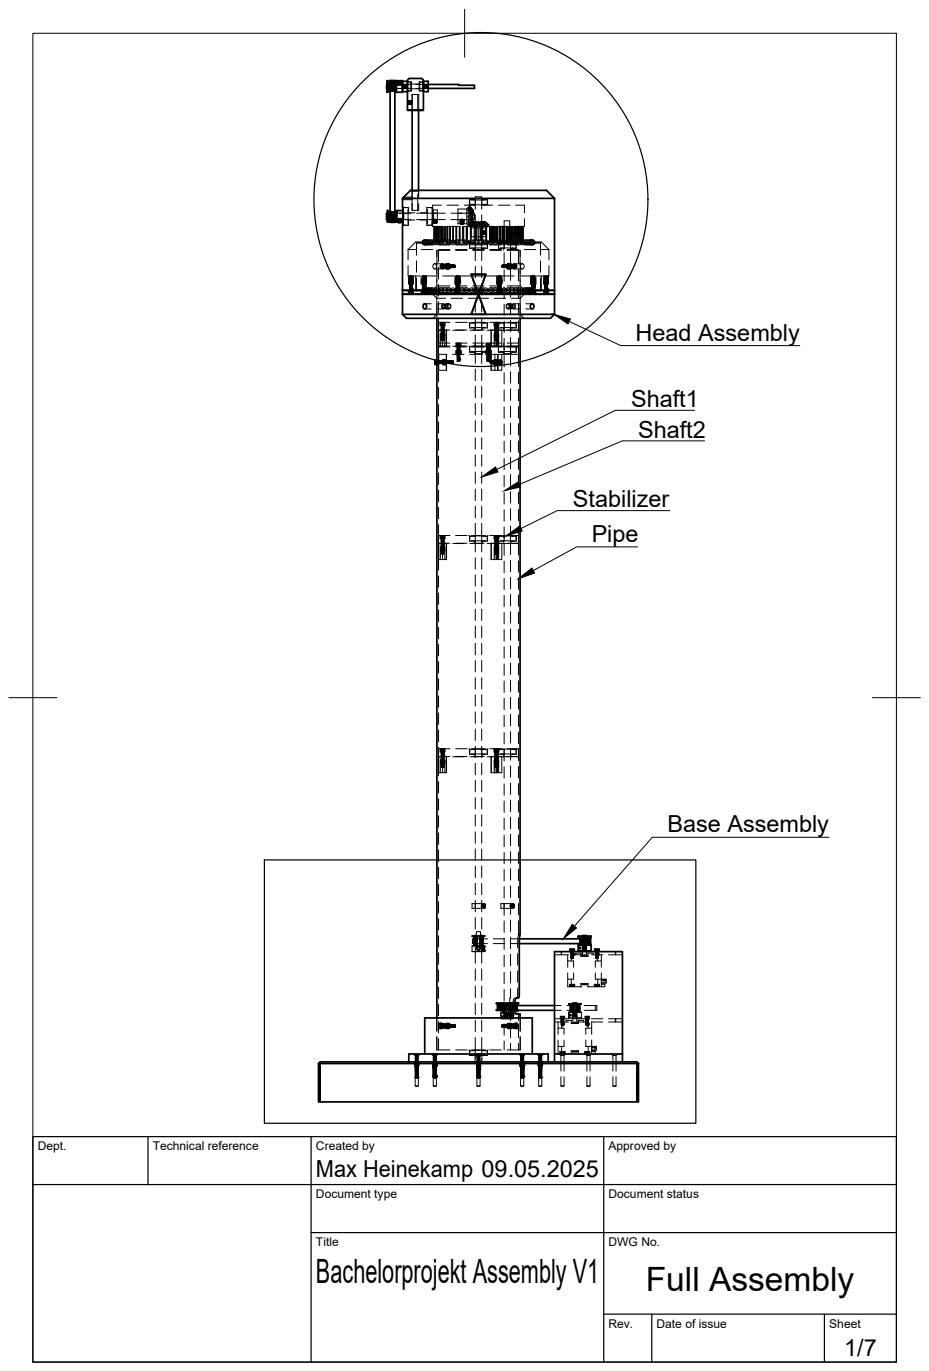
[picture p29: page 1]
Dept.; Technical reference; Created by; Approved by; Document type; Document status; Title; DWG No.; Rev.; Date of issue; Sheet; Bachelorprojekt Assembly V1; Full Assembly; Max Heinekamp; Head Assembly; Base Assembly

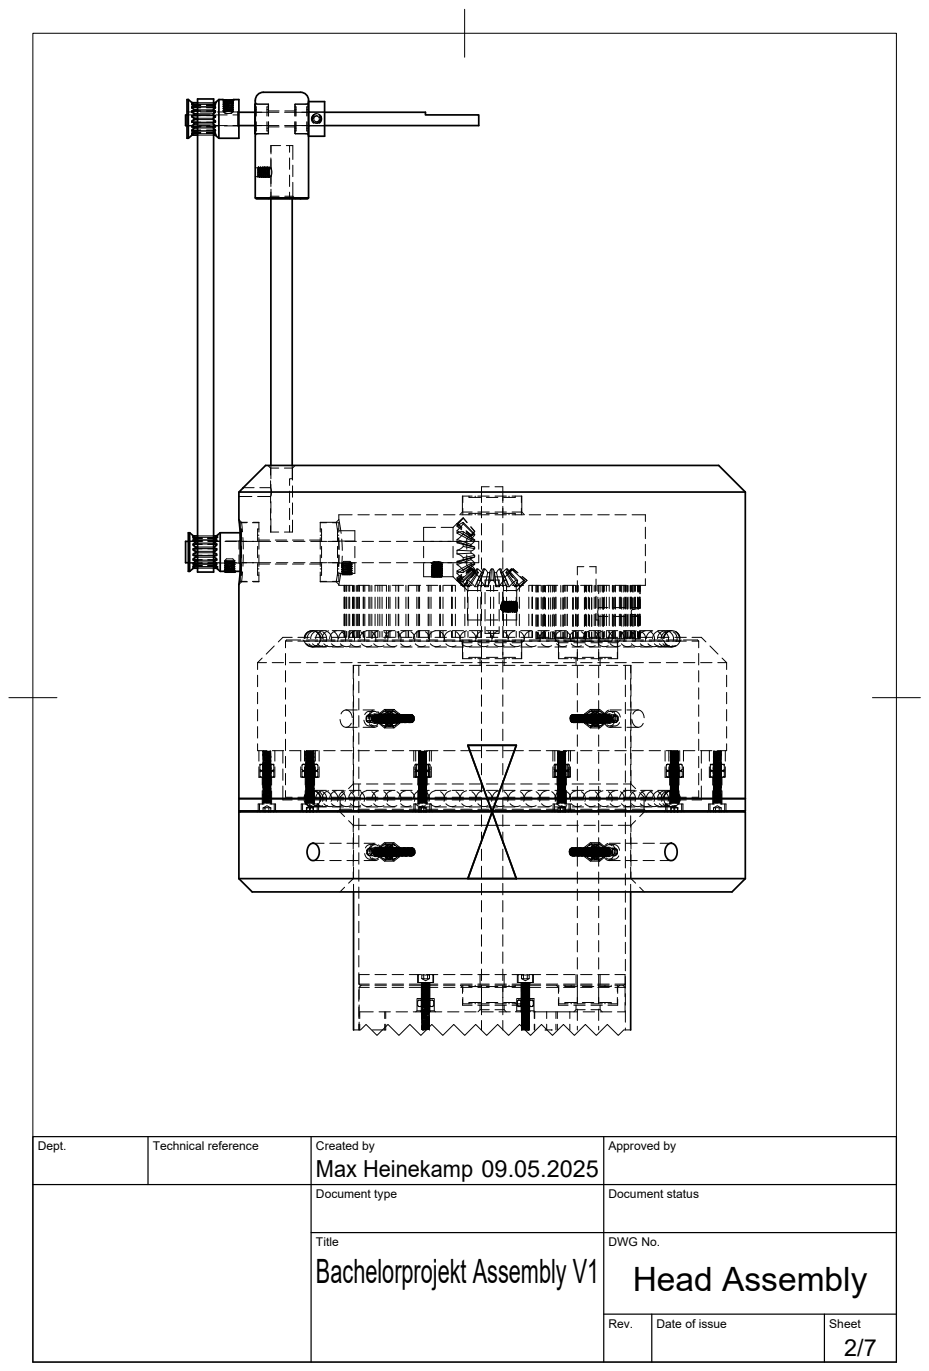
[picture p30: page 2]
Dept.; Technical reference; Created by; Approved by; Document type; Document status; Title; DWG No.; Max Heinekamp

Bachelorprojekt Assembly V1 Head Assembly

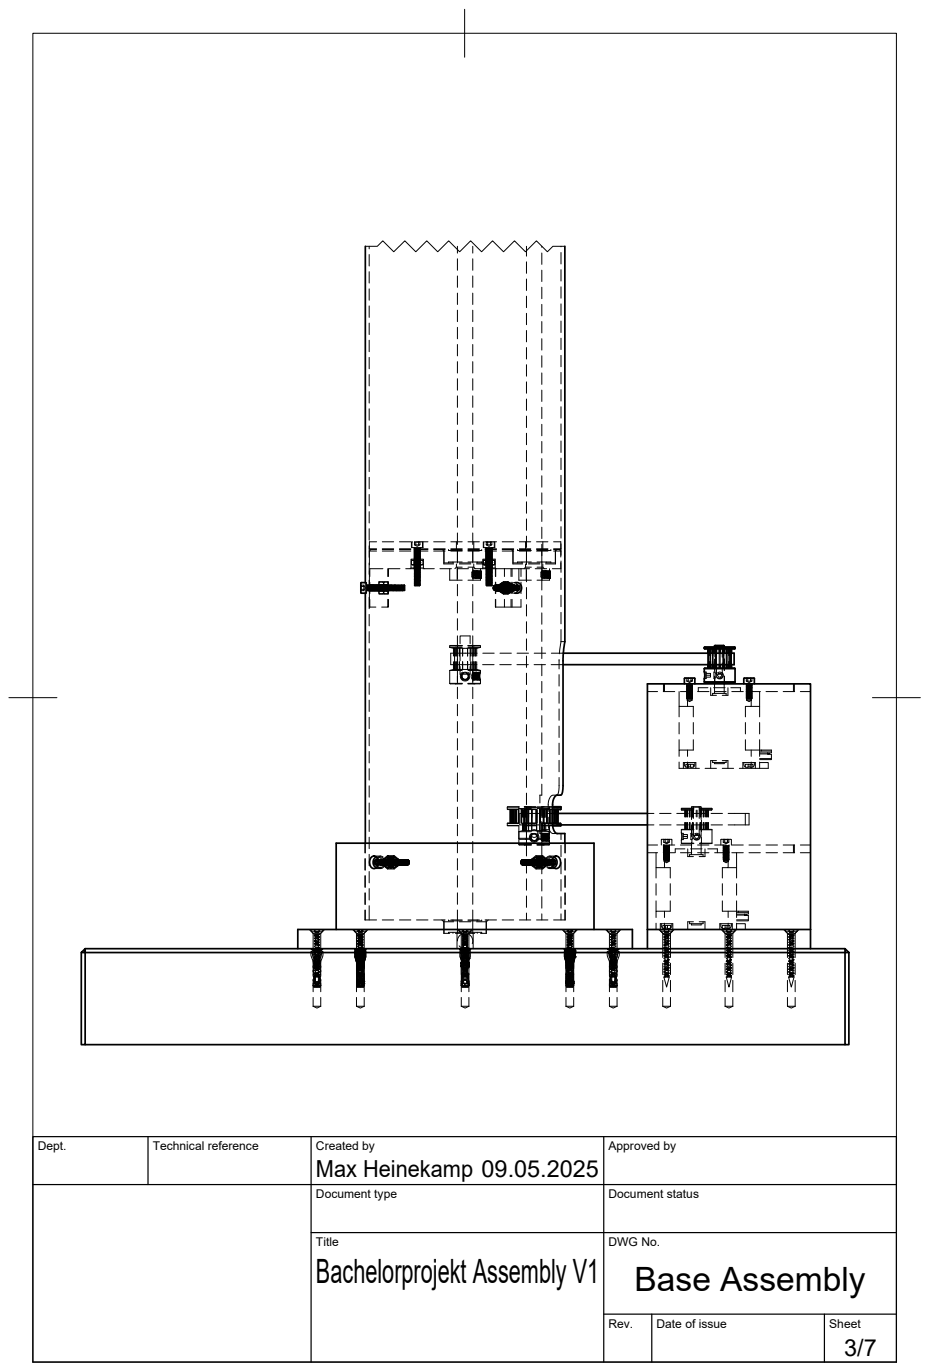
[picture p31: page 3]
Dept.; Technical reference; Created by; Approved by; Document type; Document status; Title; DWG No.; Max Heinekamp

Bachelorprojekt Assembly V1 Base Assembly

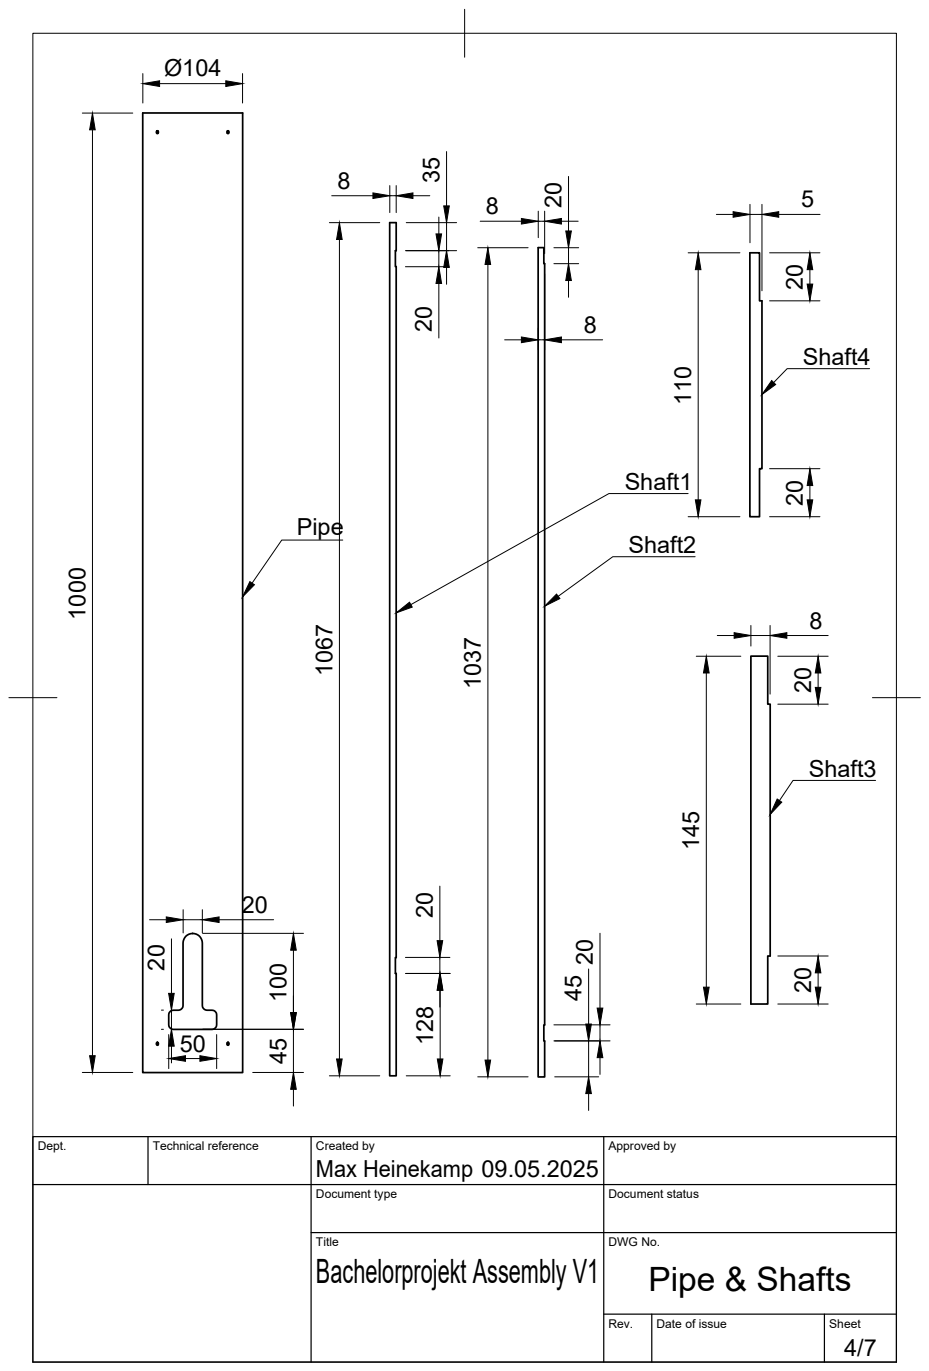
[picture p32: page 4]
Max Heinekamp 1000

Dept. | Technical reference | Created by 09.05.2025 | Approved by

Document type | Document status

Title Bachelorprojekt Assembly V1 | DWG No. Pipe & Shafts

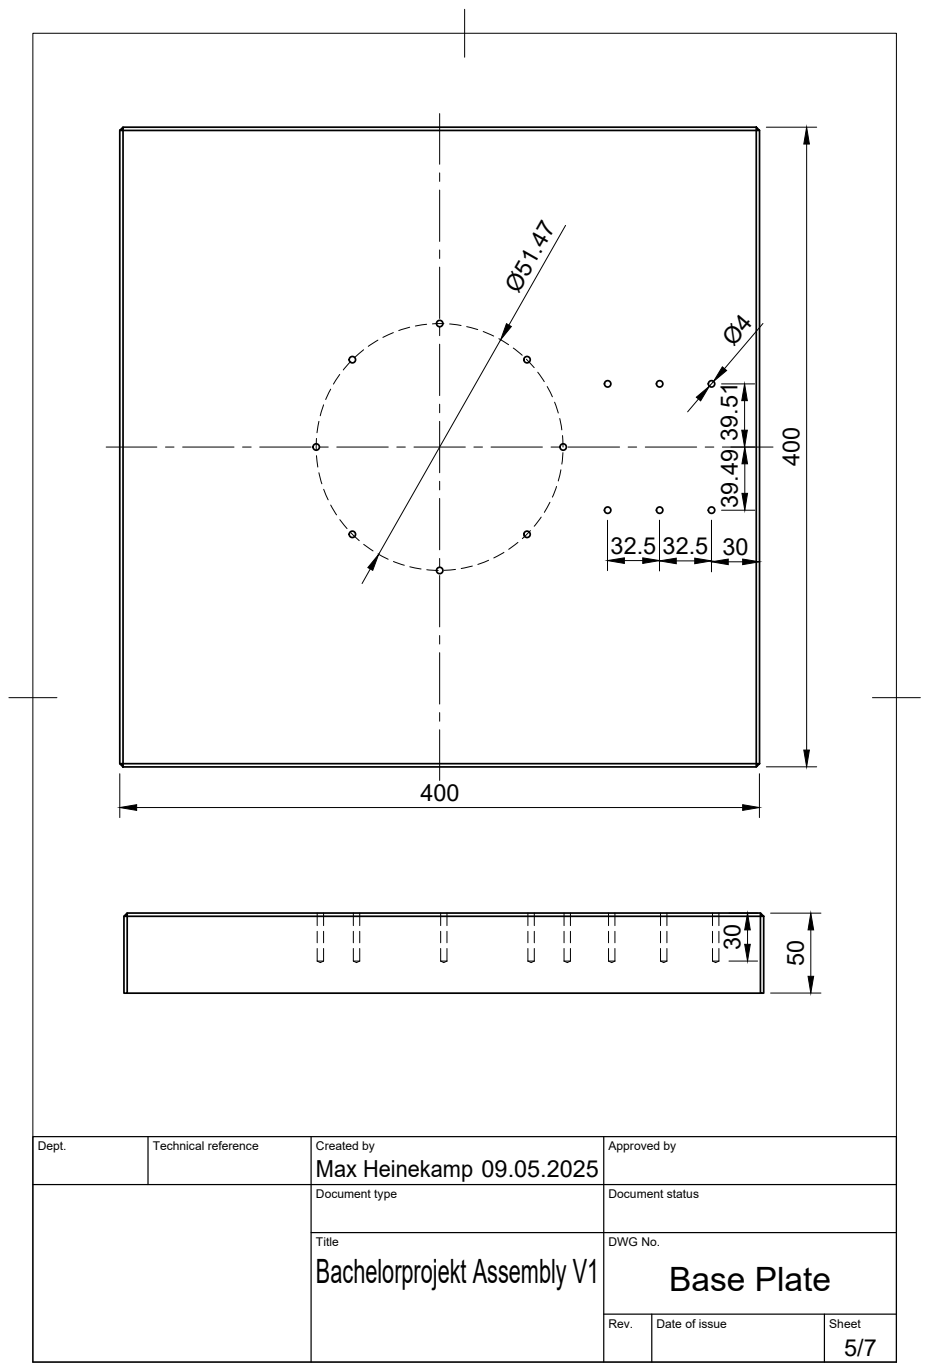
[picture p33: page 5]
Max Heinekamp

Dept. | Technical reference | Created by 09.05.2025 | Approved by

Document type | Document status

Title Bachelorprojekt Assembly V1 | DWG No. Base Plate

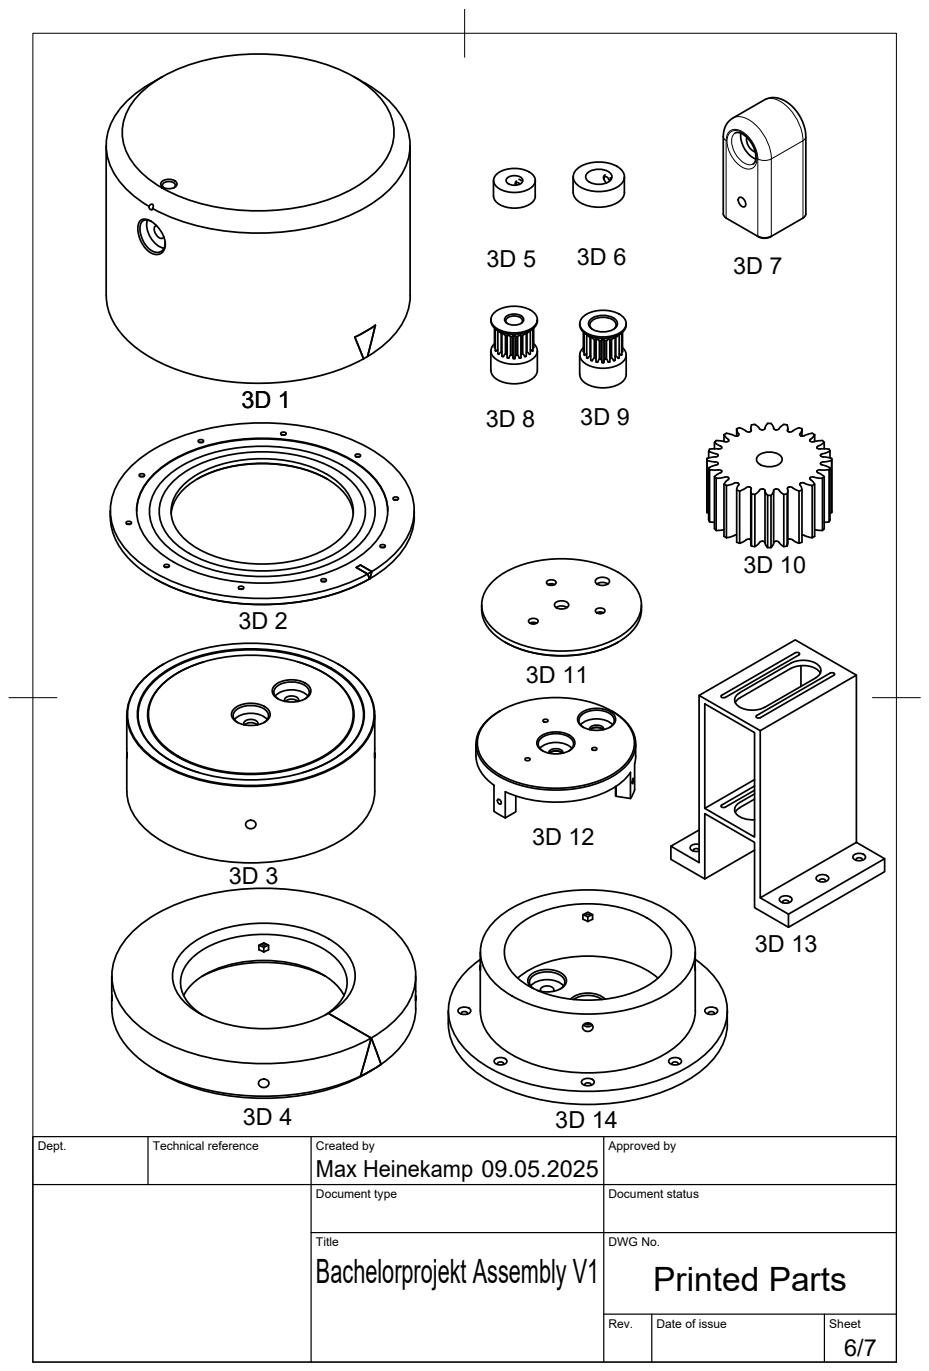
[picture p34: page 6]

Dept. | Technical reference | Created by Max Heinekamp 09.05.2025 | Approved by

Document type | Document status

Title Bachelorprojekt Assembly V1 | DWG No. Printed Parts

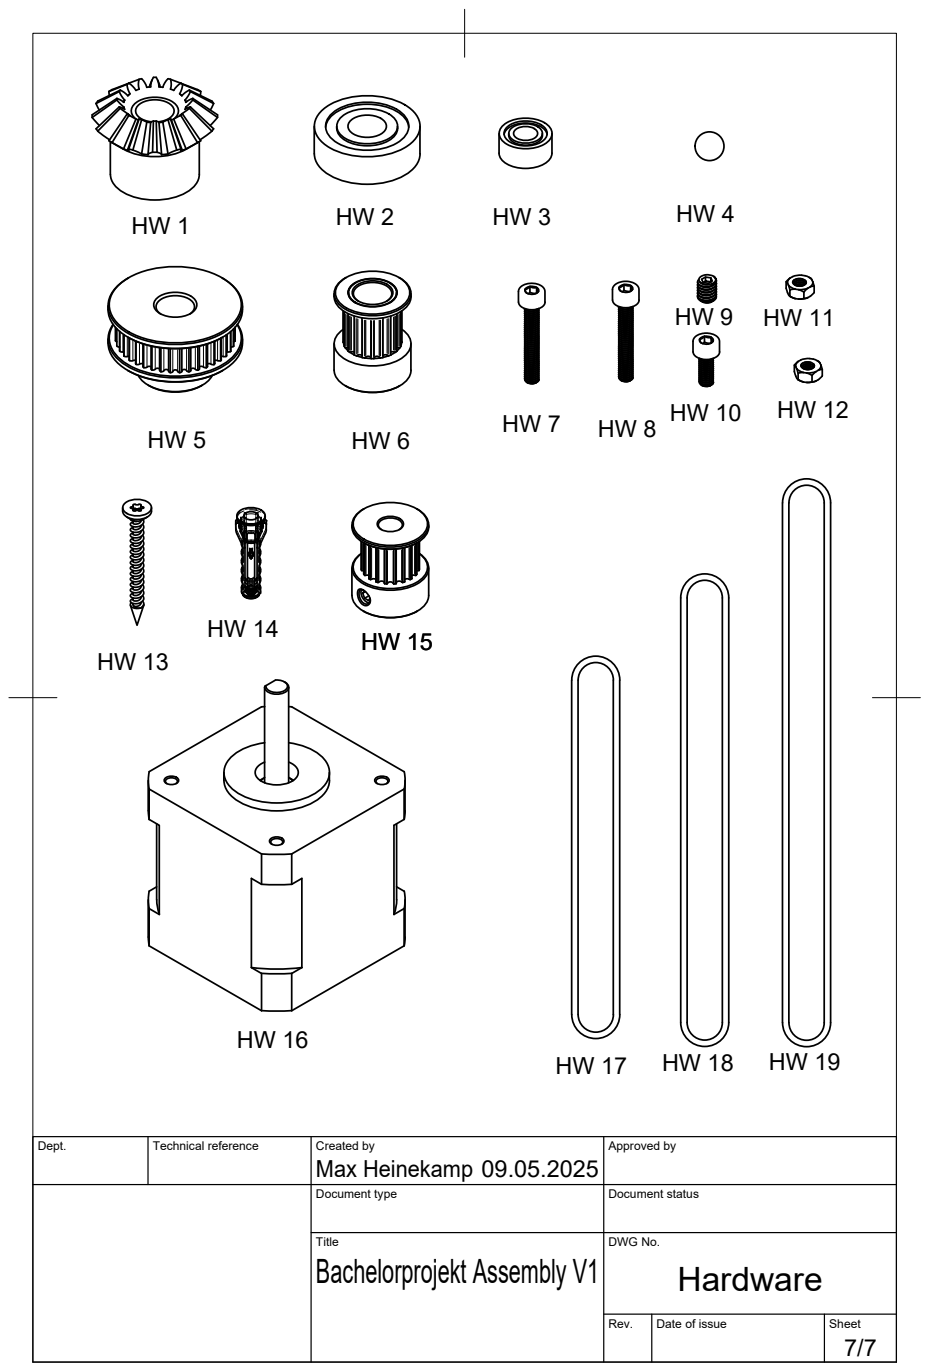
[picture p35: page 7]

Dept. | Technical reference | Created by Max Heinekamp 09.05.2025 | Approved by

Document type | Document status

Title Bachelorprojekt Assembly V1 | DWG No. Hardware

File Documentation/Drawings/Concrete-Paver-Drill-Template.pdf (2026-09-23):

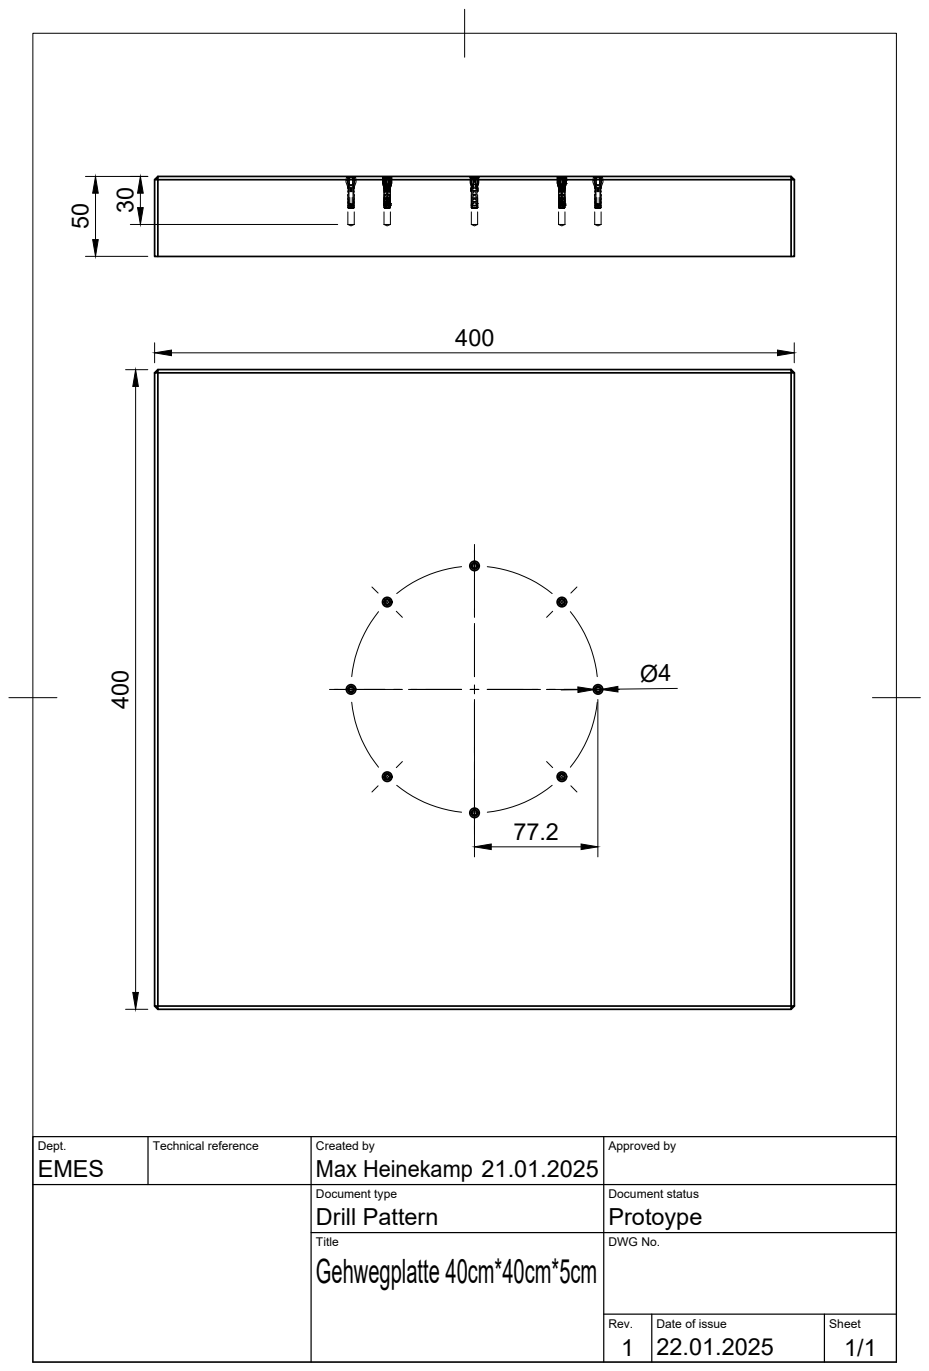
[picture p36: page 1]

Dept. EMES | Technical reference | Created by Max Heinekamp 21.01.2025 | Approved by

Document type Drill Pattern | Document status Protoype

Title Gehwegplatte 40cm*40cm*5cm | DWG No.

Rev. 1 | Date of issue 22.01.2025 | Sheet 1/1

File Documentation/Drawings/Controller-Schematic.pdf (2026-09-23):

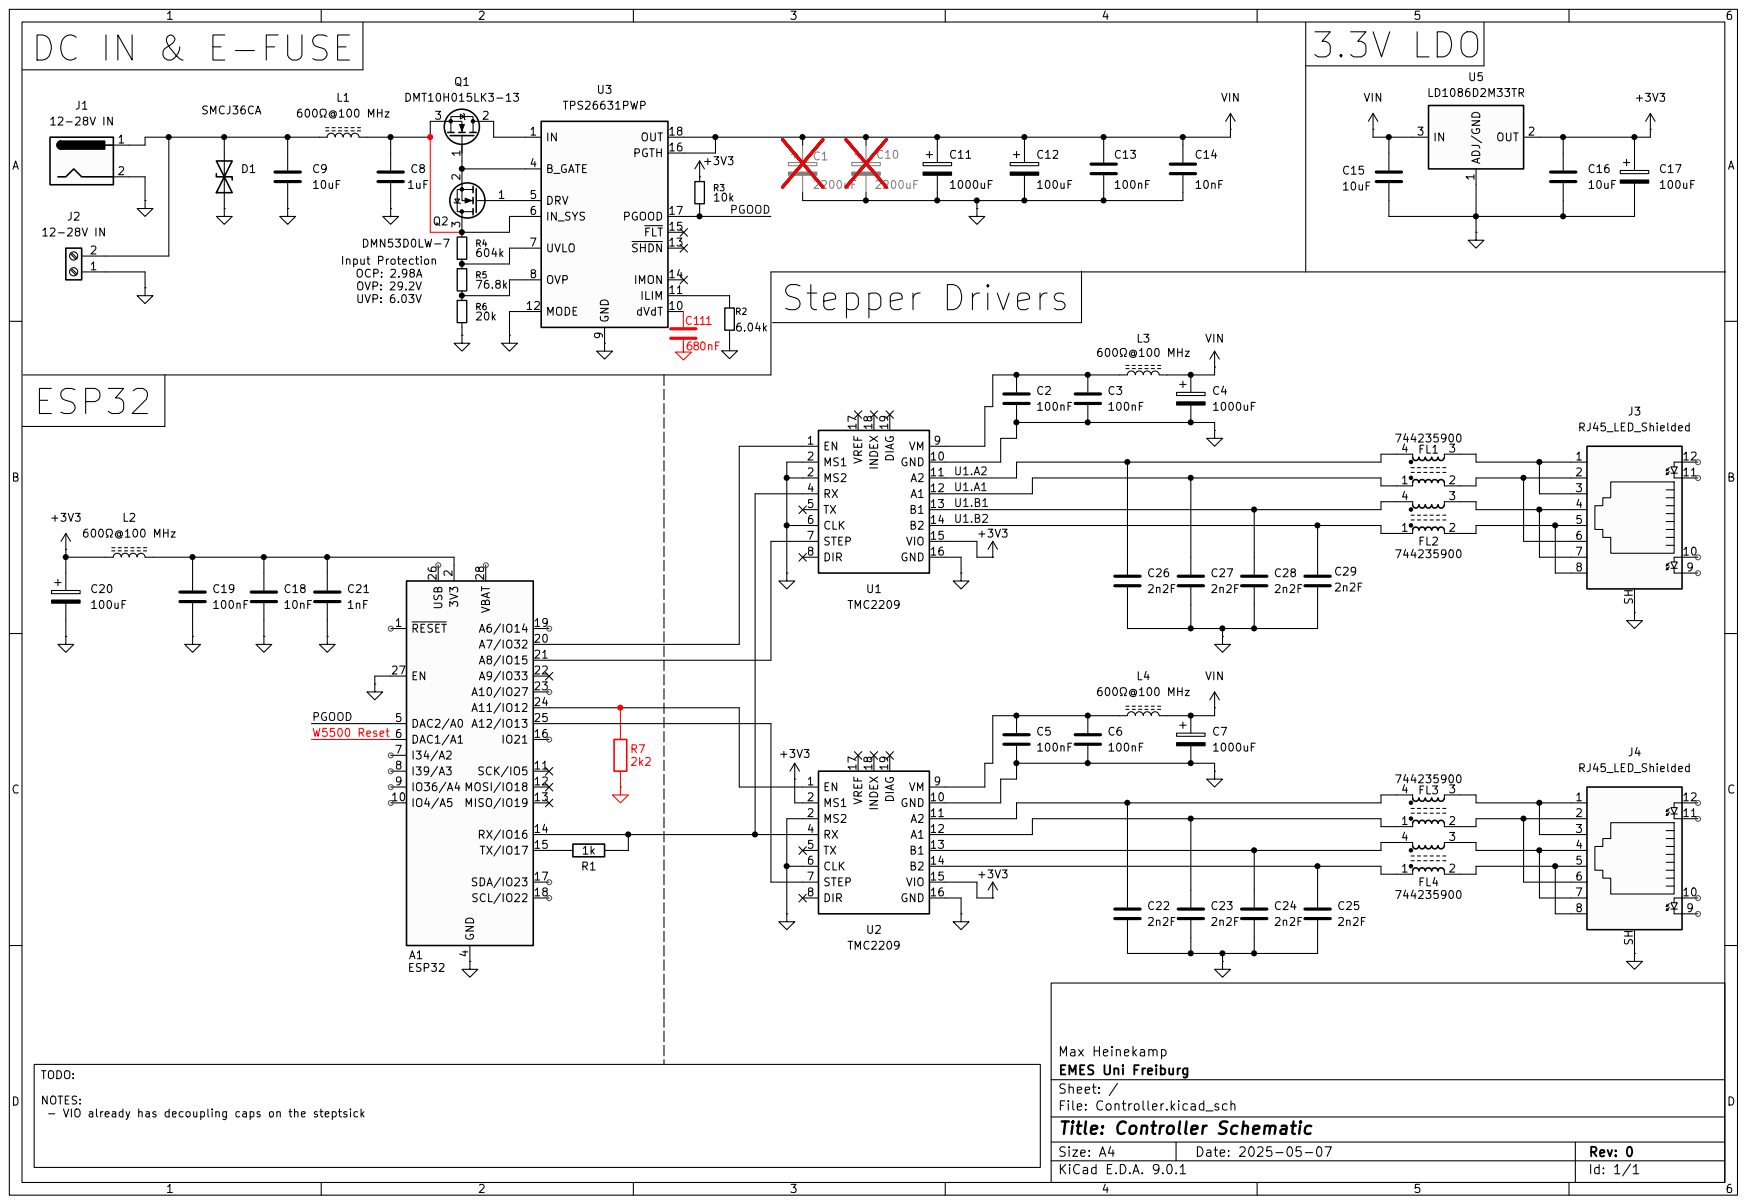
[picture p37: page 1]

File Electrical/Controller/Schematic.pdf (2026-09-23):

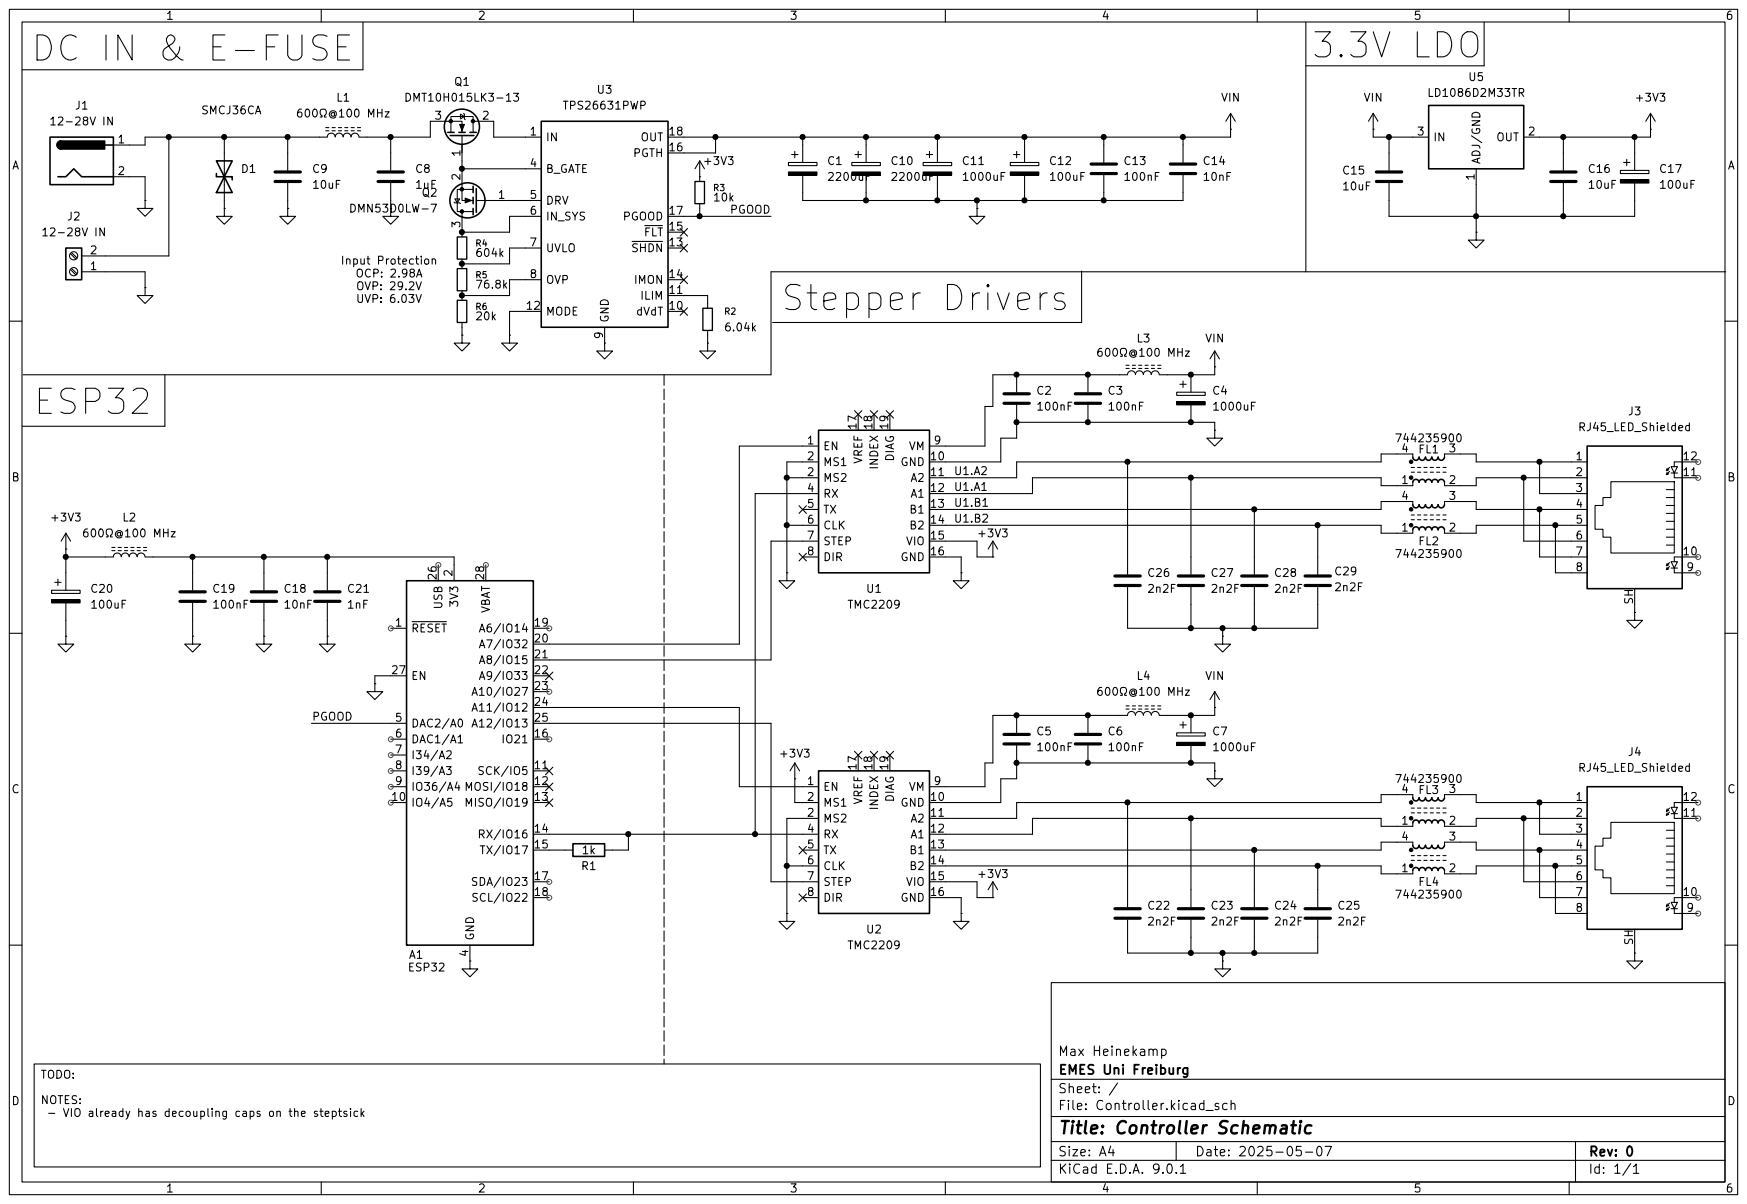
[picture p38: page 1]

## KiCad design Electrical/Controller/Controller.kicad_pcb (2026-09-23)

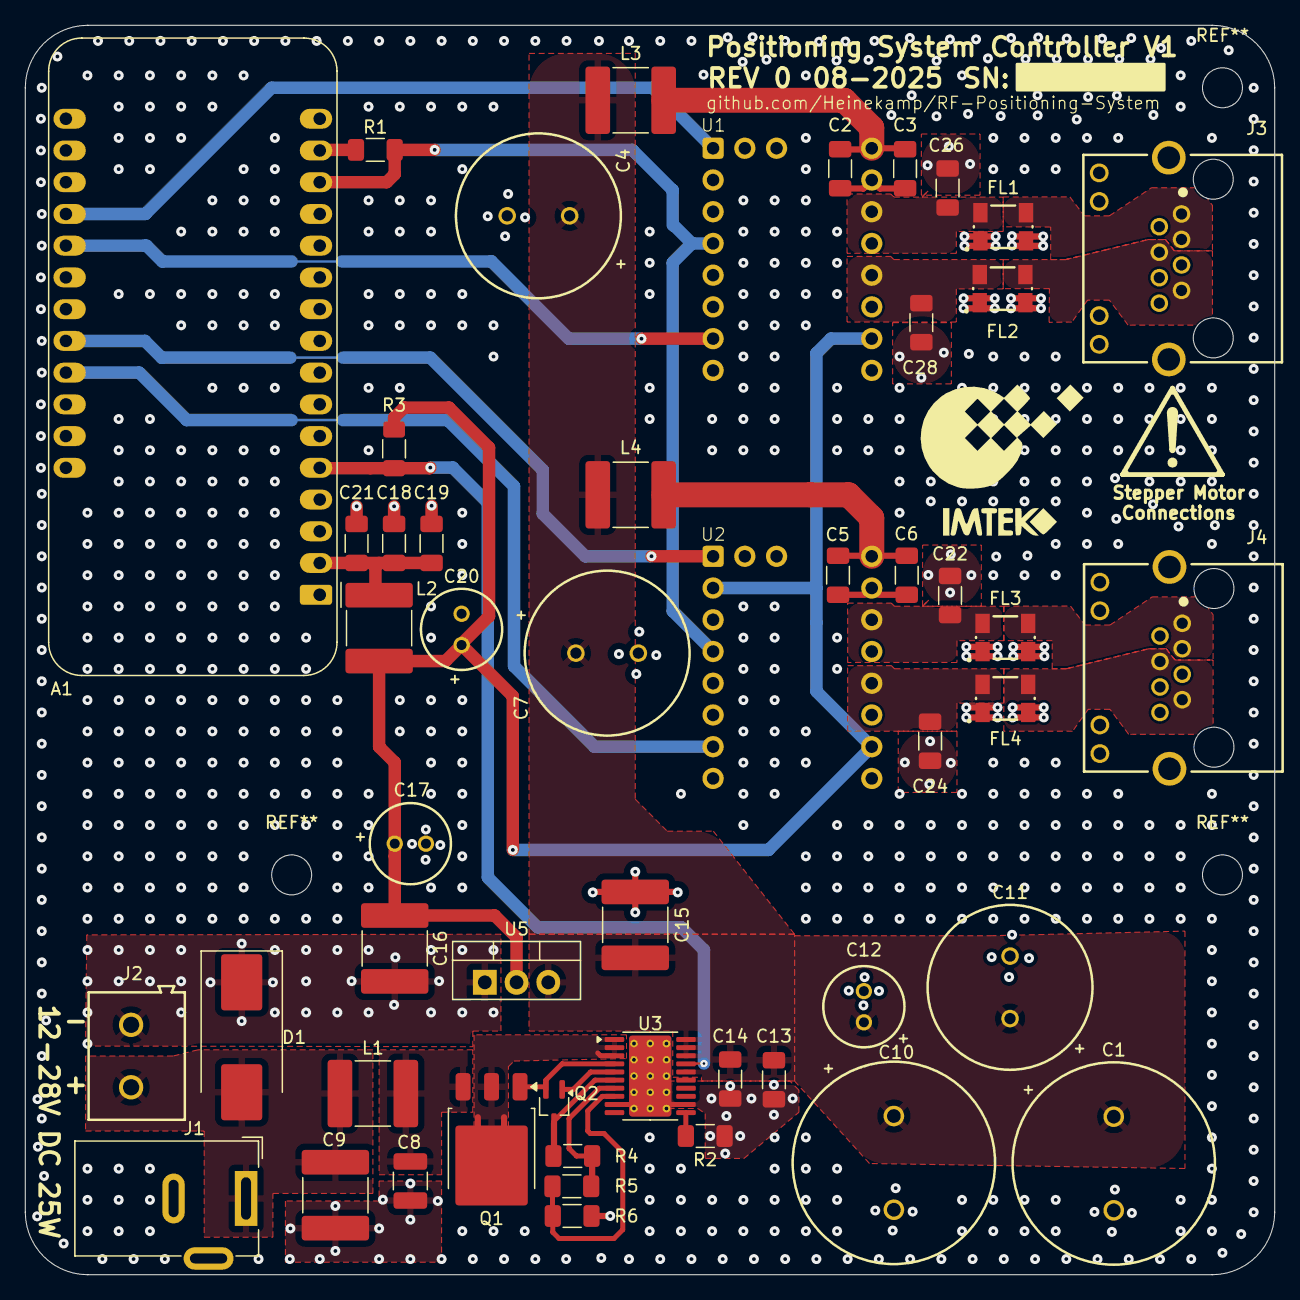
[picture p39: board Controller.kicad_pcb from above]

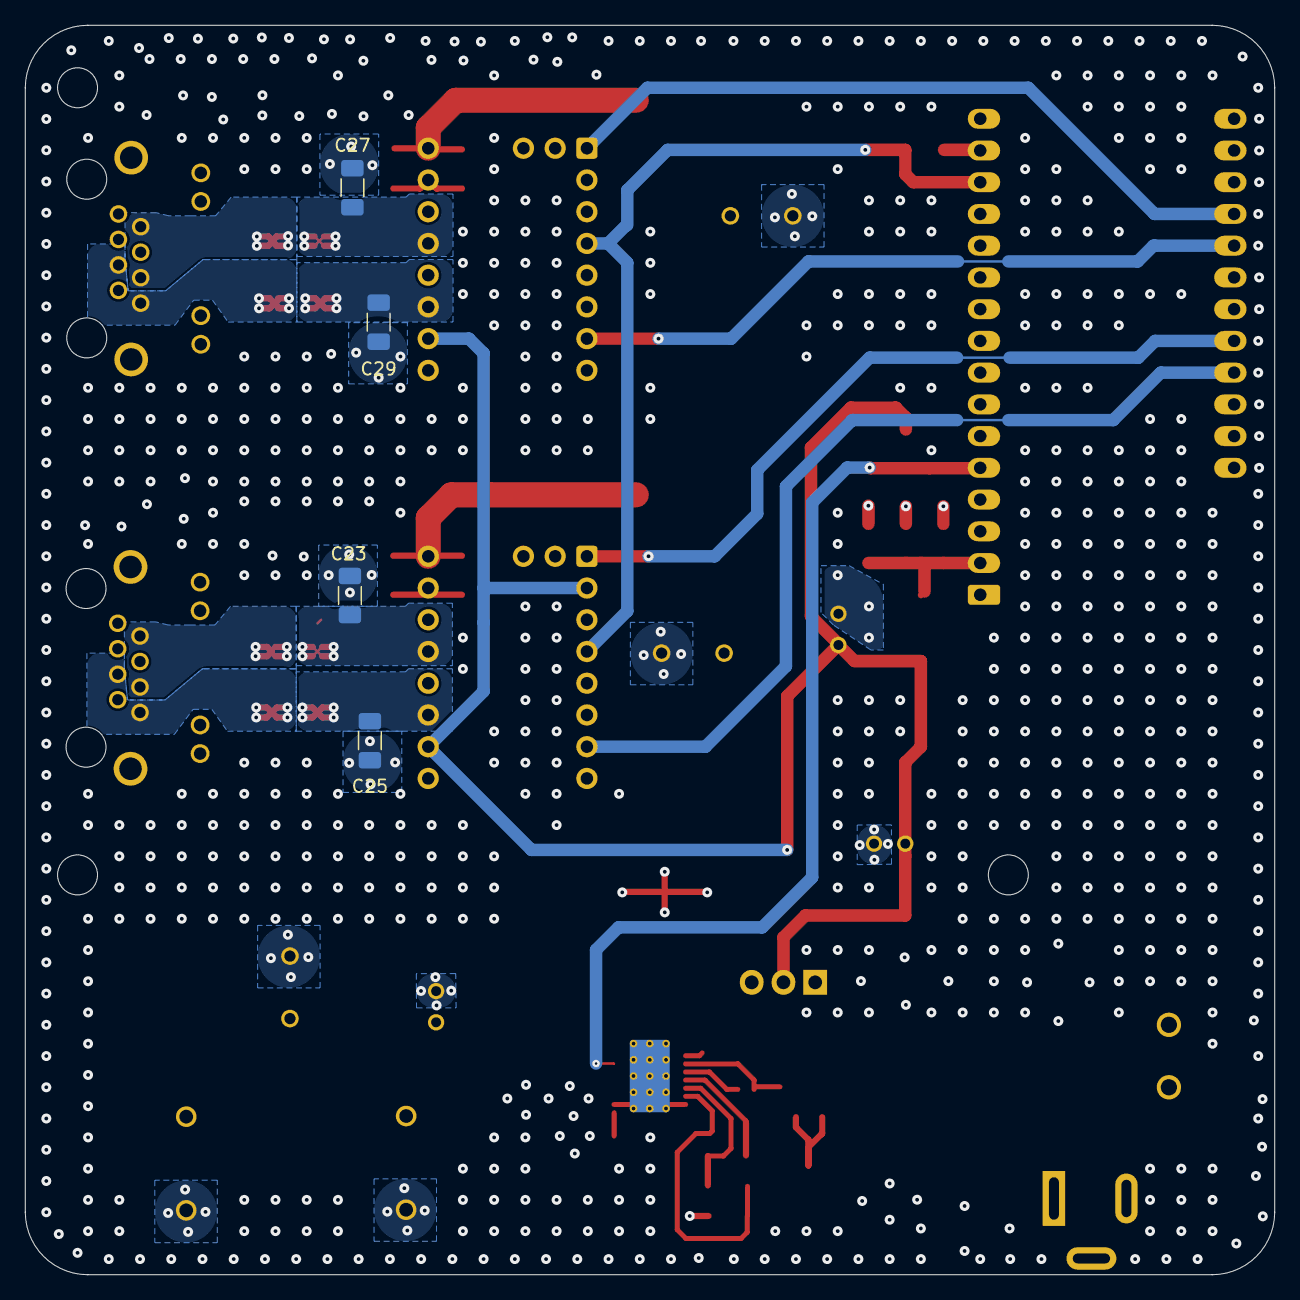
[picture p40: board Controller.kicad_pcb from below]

Board: 4 copper layers, 100.0 x 100.0 mm, 55 parts (4 on the bottom side), 38 nets.

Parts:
A1: ESP32; Adafruit_Feather_ESP32
C1, C10: 2200uF; WCAP-ATG8_16X25_DXL_
C2, C3, C5, C6, C13, C19: 100nF; C_1206_3216Metric_Pad1.33x1.80mm_HandSolder
C4, C7, C11: 1000uF; WCAP-ATUL_13X25_DXL_
C8: 1uF; C_1210_3225Metric_Pad1.33x2.70mm_HandSolder
C9, C15, C16: 10uF; C_2220_5750Metric_Pad1.97x5.40mm_HandSolder
C12, C17, C20: 100uF; WCAP-ATG8_6.3X11_DXL_
C14, C18: 10nF; C_1206_3216Metric_Pad1.33x1.80mm_HandSolder
C21: 1nF; C_1206_3216Metric_Pad1.33x1.80mm_HandSolder
C22, C23, C24, C25, C26, C27, C28, C29: 2n2F; C_1206_3216Metric_Pad1.33x1.80mm_HandSolder
D1: SMCJ36CA; D_SMC_Handsoldering
FL1, FL2, FL3, FL4: 744235900; WE-CNSW_1812
J1: 12-28V IN; BarrelJack_Wuerth_6941xx301002
J2: Screw_Terminal_01x02; 691502710002
J3, J4: RJ45_LED_Shielded; Wuerth 615008137421
L1, L2, L3, L4: 600Ω@100 MHz; C_2220_5750Metric_Pad1.97x5.40mm_HandSolder
Q1: DMT10H015LK3-13; TO-252-3_TabPin2
Q2: DMN53D0LW-7; SOT-323_SC-70_Handsoldering
R1: 1k; R_1206_3216Metric_Pad1.30x1.75mm_HandSolder
R2: 6.04k; R_1206_3216Metric_Pad1.30x1.75mm_HandSolder
R3: 10k; R_1206_3216Metric_Pad1.30x1.75mm_HandSolder
R4: 604k; R_1206_3216Metric_Pad1.30x1.75mm_HandSolder
R5: 76.8k; R_1206_3216Metric_Pad1.30x1.75mm_HandSolder
R6: 20k; R_1206_3216Metric_Pad1.30x1.75mm_HandSolder
U1, U2: TMC2209; BTT-TMC2209-V1.3
U3: TPS26631PWP; HTSSOP-20-1EP_4.4x6.5mm_P0.65mm_EP3.4x6.5mm_Mask2.75x3.43mm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
U5: LD1086D2M33TR; TO-220-3_Vertical-v8508a

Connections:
+3V3: C16.1, C17.1, C20.1, L2.1, R3.1, U1.15 (VIO), U2.2 (MS1), U2.15 (VIO), U5.2 (OUT)
/PGOOD: A1.5 (DAC2/A0), R3.2, U3.17 (PGOOD)
/U1.A1: C27.1, FL1.1, U1.12 (A1)
/U1.A2: C26.1, FL1.4, U1.11 (A2)
/U1.B1: C28.1, FL2.4, U1.13 (B1)
/U1.B2: C29.1, FL2.1, U1.14 (B2)
GND: A1.4 (GND), A1.27 (EN), C1.2, C2.2, C3.2, C4.2, C5.2, C6.2, C7.2, C8.2, C9.2, C10.2, C11.2, C12.2, C13.2, C14.2, C15.2, C16.2, C17.2, C18.2, C19.2, C20.2, C21.2, C22.2, C23.2, C24.2, C25.2, C26.2, C27.2, C28.2, C29.2, D1.1 (A1), J1.2, J2.1, R2.2, R6.2, U1.2 (MS2), U1.6 (CLK), U1.10 (GND), U1.16 (GND), U2.6 (CLK), U2.10 (GND), U2.16 (GND), U3.9 (GND), U3.12 (MODE), U3.21 (GND), U5.1 (ADJ/GND)
unnamed: A1.2 (3V3), C18.1, C19.1, C21.1, L2.2
unnamed: A1.20 (A7/IO32), U1.1 (EN)
unnamed: A1.21 (A8/IO15), U1.7 (STEP)
unnamed: A1.24 (A11/IO12), U2.1 (EN)
unnamed: A1.25 (A12/IO13), U2.7 (STEP)
unnamed: A1.14 (RX/IO16), R1.2, U1.4 (RX), U2.4 (RX)
unnamed: A1.15 (TX/IO17), R1.1
unnamed: C8.1, L1.2, Q1.3 (S)
unnamed: C9.1, D1.2 (A2), J1.1, J2.2, L1.1
unnamed: FL1.2, J3.2, J3.6
unnamed: FL1.3, J3.1, J3.3
unnamed: FL2.2, J3.5, J3.8
unnamed: FL2.3, J3.4, J3.7
unnamed: FL3.2, J4.2, J4.6
unnamed: FL3.3, J4.1, J4.3
unnamed: FL4.2, J4.5, J4.8
unnamed: FL4.3, J4.4, J4.7
unnamed: Q1.2 (D), U3.1 (IN), U3.2 (IN), U3.3 (IN)
unnamed: Q1.1 (G), Q2.2 (S), U3.4 (B_GATE)
unnamed: Q2.3 (D), R4.1, U3.6 (IN_SYS)
unnamed: Q2.1 (G), U3.5 (DRV)
unnamed: C2.1, C3.1, L3.1, U1.9 (VM)
unnamed: C23.1, FL3.1, U2.12 (A1)
unnamed: C22.1, FL3.4, U2.11 (A2)
unnamed: C24.1, FL4.4, U2.13 (B1)
unnamed: C25.1, FL4.1, U2.14 (B2)
unnamed: C5.1, C6.1, L4.1, U2.9 (VM)
unnamed: R2.1, U3.11 (ILIM)
unnamed: R5.2, R6.1, U3.8 (OVP)
unnamed: R4.2, R5.1, U3.7 (UVLO)
VIN: C1.1, C4.1, C7.1, C10.1, C11.1, C12.1, C13.1, C14.1, C15.1, L3.2, L4.2, U3.16 (PGTH), U3.18 (OUT), U3.19 (OUT), U3.20 (OUT), U5.3 (IN)

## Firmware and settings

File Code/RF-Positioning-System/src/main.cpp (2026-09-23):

/**
 * @file main.cpp
 * @author Max Heinekamp
 * @brief main file for the project.
 * @version 0.1
 * @date 27-01-2025
 * 
 * @copyright Copyright (c) 2025
 * 
 */

// Include required libraries
#include <Arduino.h>
#include "config.h"
#include "Vrekrer_scpi_parser.h"
#include "scpi.h"
#include "flash.h"
#include "esp_system.h"

//Sored in RTC memory to persist across soft resets, but not power cycles. Used to determine if the system has just booted or if it has been reset after boot.
RTC_DATA_ATTR bool hasResetAfterBoot = false;

//Sored in RTC memory to persist across soft resets, but not power cycles. Counts boots since the
//device was last fully power-cycled, so repeated involuntary resets (e.g. brownouts, watchdog
//triggers) during otherwise-normal operation are visible via DIAGnostic:SYStem?.
RTC_DATA_ATTR uint32_t bootCount = 0;


//Create Flash object
FLASH flash_memory;

// Cretate global pointers for SCPI and Stepper objects
SCPI* scpi_instrument = nullptr;
STEPPER* stepper1 = nullptr;
STEPPER* stepper2 = nullptr;

const char* resetReasonToString(esp_reset_reason_t reason) {
  switch (reason) {
    case ESP_RST_UNKNOWN: return "UNKNOWN";
    case ESP_RST_POWERON: return "POWERON";
    case ESP_RST_EXT: return "EXT";
    case ESP_RST_SW: return "SW";
    case ESP_RST_PANIC: return "PANIC";
    case ESP_RST_INT_WDT: return "INT_WDT";
    case ESP_RST_TASK_WDT: return "TASK_WDT";
    case ESP_RST_WDT: return "WDT";
    case ESP_RST_DEEPSLEEP: return "DEEPSLEEP";
    case ESP_RST_BROWNOUT: return "BROWNOUT";
    case ESP_RST_SDIO: return "SDIO";
    default: return "UNMAPPED";
  }
}


void setup() {
  bootCount++;

  pinMode(POWER_GOOD_PIN, INPUT); // Not currently used

  flash_memory.initFlashMemory();

  scpi_instrument = new SCPI();

  //Retrieve ethernet settings from flash memory
  int ethernet_reset_pin = flash_memory.preferences.getInt("ETHERNET-RESET-PIN", ETHERNET_RESET_PIN);

  //Wait for power to stabilize and then reset ethernet module
  delay(500);
  pinMode(ethernet_reset_pin, OUTPUT);
  digitalWrite(ethernet_reset_pin, LOW);
  delay(100);
  digitalWrite(ethernet_reset_pin, HIGH);
  delay(500);

  // Retrieve stepper settings from flash memory
  int address1 = flash_memory.preferences.getInt("STEPPER1-ADDRESS", STEPPER1_ADDRESS);
  int address2 = flash_memory.preferences.getInt("STEPPER2-ADDRESS", STEPPER2_ADDRESS);
  int step_pin1 = flash_memory.preferences.getInt("MOTOR1-STEP-PIN", MOTOR1_STEP_PIN);
  int enable_pin1 = flash_memory.preferences.getInt("MOTOR1-ENABLE-PIN", MOTOR1_ENABLE_PIN);
  int step_pin2 = flash_memory.preferences.getInt("MOTOR2-STEP-PIN", MOTOR2_STEP_PIN);
  int enable_pin2 = flash_memory.preferences.getInt("MOTOR2-ENABLE-PIN", MOTOR2_ENABLE_PIN);
  
  // Initialize stepper objects with the retrieved settings
  stepper1 = new STEPPER(address1, step_pin1, enable_pin1);
  stepper2 = new STEPPER(address2, step_pin2, enable_pin2);

  // Start serial communication for USB interface
  Serial.begin(9600);
   // Start serial interface for stepper motor driver
  Serial1.begin(9600);
  //Setup SCPI communication
  scpi_instrument->setup();
  
  //Setup Stepper motor
  stepper1->setup();
  stepper2->setup();

  esp_reset_reason_t resetReason = esp_reset_reason();
  Serial.println("Test123");
  delay(500);
  Serial.println("Test1234");
  delay(500);
  Serial.printf("Reset reason: %d\n", esp_reset_reason());

  if ((resetReason == ESP_RST_POWERON || resetReason == ESP_RST_BROWNOUT || resetReason == ESP_RST_UNKNOWN || resetReason == ESP_RST_EXT) && hasResetAfterBoot == false) {
    Serial.println("Cold/unstable boot detected, scheduling hardware reset...");
    Serial.flush();  // Ensure message is sent before reset

    hasResetAfterBoot = true;
    
    delay(5000);  // wait for power to stabilize
    
    esp_restart();
    
    // // Perform hardware reset by pulling EN pin low via GPIO
    // pinMode(RESET_CONTROL_PIN, OUTPUT);
    // digitalWrite(RESET_CONTROL_PIN, LOW);
    // delay(500);  // Hold low long enough for reset
    // digitalWrite(RESET_CONTROL_PIN, HIGH);  // Release (safety, though we're gone by now)
    
  }
}
  
void loop() {
  //Check Serial for incoming SCPI commands 
  scpi_instrument->processSerial();
  //Check Ethernet for incoming SCPI commands
  scpi_instrument->processEthernet();
  
}

/*
import pyvisa
rm = pyvisa.ResourceManager('@py')
EthInstrument = rm.open_resource('TCPIP0::192.168.0.13::5025::SOCKET')
EthInstrument.write_termination = '\n'
EthInstrument.read_termination = '\n'
EthInstrument.query("*IDN?") 
*/

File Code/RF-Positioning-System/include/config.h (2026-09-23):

/**
 * @file config.h
 * @author Max Heinekamp
 * @brief Configuration file for the entire project.
 * @note This information will be copied to the flash memory of the ESP32 on first boot by FLASH::initFlashMemory()
 * @version 0.1
 * @date 26-01-2025
 * 
 * @copyright Copyright (c) 2025
 * 
 */

#ifndef CONFIG_H
#define CONFIG_H

#include "Ethernet.h"

// SCPI parser command-hash width. The Vrekrer SCPI parser's default hash type (uint8_t) has
// only 256 possible values; with ~35 registered commands spanning a multi-level tree, hash
// collisions are a real risk. Confirmed: under uint8_t, "CONFigure:MOTor" itself hashes to
// exactly 0, which the parser's own code treats as its "no tree base set" sentinel, silently
// breaking every command registered under that entire branch (RMScurrent, HOLDcurrent,
// MICROsteps, SPEED, ACCELeration and their queries). Must be defined before
// Vrekrer_scpi_parser.h is first included anywhere in the project (this file is included
// ahead of the parser everywhere it's used).
#define SCPI_HASH_TYPE uint16_t

///////////////////////////////////////////////////////////////////////////////
// DEVICE INFORMATION                                                       //
/////////////////////////////////////////////////////////////////////////////

#define DEVICE_MANUFACTURER "EMES"
#define DEVICE_NAME "RF-Positioning-System"
#define DEVICE_VERSION "1.0.0"
#define DEVICE_SERIAL "001"
#define POWER_GOOD_PIN 26 // Output from the eFuse, not currently used

// SCPI server settings
#define SCPI_PORT 5025
#define IP_ADDRESS "192.168.0.55"
#define MAC_ADDRESS { 0xDE, 0xAD, 0xBE, 0xEF, 0xFE, 0xED }
#define ERROR_QUEUE_SIZE 10

// Ethernet module settings
#define ETHERNET_RESET_PIN 25

// Hardware reset control
#define RESET_CONTROL_PIN 4  // GPIO pin to pull EN low for hardware reset

// Stepper motor settings
#define STEPS_PER_REV 200
#define MOTOR1_STEP_PIN 15
#define MOTOR1_ENABLE_PIN 32
#define MOTOR2_STEP_PIN 13
#define MOTOR2_ENABLE_PIN 12
#define MOTOR_SERIAL_PORT Serial1
#define R_SENSE 0.11f
#define STEP_DELAY 4 // Was 160
#define RMS_CURRENT 1600 // in mA
#define HOLD_CURRENT 8 // as a fraction /32 of RMS_CURRENT
#define MICROSTEPS 16 // 1/16th microstepping
#define STEPPER1_ADDRESS 0
#define STEPPER2_ADDRESS 1
#define AXIS1_GEAR_RATIO 1
#define AXIS2_GEAR_RATIO 6
#define AXIS2_DIR_CHANGE_CAL_FACTOR 3 // degrees to drive for backlash compensation
#define SPEED 1000 // in steps/s
#define ACCELERATION 5000 // in steps/s^2


#endif // CONFIG_H

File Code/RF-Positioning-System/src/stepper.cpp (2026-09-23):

/**
 * @file stepper.cpp
 * @author Max Heinekamp
 * @brief This file contains the function definitions for the STEPPER class, which handles the stepper motor control.
 * @details The STEPPER class uses the TMCStepper library to interface with the stepper motor driver. It provides methods to control the motor's movement, direction, and configuration settings.
 * @version 0.1
 * @date 29-04-2025
 * 
 * @copyright Copyright (c) 2025
 * 
 */

#include "stepper.h"
#include "flash.h"

extern FLASH flash_memory;

STEPPER::STEPPER(int address, int step_pin, int enable_pin) : 
    address(address),
    step_pin(step_pin),
    enable_pin(enable_pin),
    stepper(&MOTOR_SERIAL_PORT, R_SENSE, address), 
    direction(false) {
}

void STEPPER::setup() {
    pinMode(step_pin, OUTPUT);
    pinMode(enable_pin, OUTPUT);

    // Enable the stepper driver
    digitalWrite(enable_pin, LOW);

    // Retrieve stepper settings from flash memory
    int microsteps = flash_memory.preferences.getInt("MICROSTEPS", MICROSTEPS);
    int hold_current = flash_memory.preferences.getInt("HOLD-CURRENT", HOLD_CURRENT);
    int rms_current = flash_memory.preferences.getInt("RMS-CURRENT", RMS_CURRENT);

    stepper.begin();
    //stepper.en_spreadCycle(true);           // Enable spreadCycle mode
    stepper.toff(5);                        // Enables driver in software
    stepper.rms_current(rms_current);       // Set motor RMS current
    stepper.ihold(hold_current);            // Set hold current to 25% of run current
    stepper.microsteps(microsteps);         // Set microsteps to 1/16th
    stepper.pwm_autoscale(true);            // Needed for stealthChop
    stepper.shaft(direction);               // Set motor direction
}

void STEPPER::step() {
    digitalWrite(step_pin, HIGH);
    delayMicroseconds(STEP_DELAY);
    digitalWrite(step_pin, LOW);
}

void STEPPER::SetDirection(bool dir) {
    stepper.shaft(dir);
    direction = dir;
}

bool STEPPER::GetDirection() {
    return direction;
}

void STEPPER::updateRMSCurrent() {
    int rms_current = flash_memory.preferences.getInt("RMS-CURRENT", RMS_CURRENT);
    stepper.rms_current(rms_current);
    updateHoldCurrent();   // rms_current() overwrites IHOLD internally; reapply the stored hold current
}

void STEPPER::updateHoldCurrent() {
    int hold_current = flash_memory.preferences.getInt("HOLD-CURRENT", HOLD_CURRENT);
    stepper.ihold(hold_current);
}

uint16_t STEPPER::getRMSCurrent() {
    return stepper.rms_current();
}

uint8_t STEPPER::getHoldCurrent() {
    return stepper.ihold();
}

void STEPPER::updateMicrosteps() {
    int microsteps = flash_memory.preferences.getInt("MICROSTEPS", MICROSTEPS);
    stepper.microsteps(microsteps);
}

void STEPPER::move(float targetSpeed, float acceleration, float angle, int steps_revolution) {
    float currentSpeed = 0;
    float stepInterval = 0;
    unsigned long lastStepTime = 0;
    unsigned long currentTime;
    int stepsTaken = 0;

    // Convert angle to steps
    float steps_degree = (float)steps_revolution / 360.0;
    float steps = angle * steps_degree;
    steps += steps_remainder;
    int steps_rounded = (int)floorf(steps);
    steps_remainder = steps - steps_rounded;

    if (steps_rounded <= 0) return; // No movement needed

    // Compute max reachable speed for triangular profile
    float maxReachableSpeed = sqrt(acceleration * steps_rounded);

    // Limit target speed if we don't have enough steps to reach it
    if (targetSpeed > maxReachableSpeed) {
        targetSpeed = maxReachableSpeed;
    }

    // Now compute acceleration distance for (possibly reduced) targetSpeed
    float accelTime = targetSpeed / acceleration;
    float accelDist = 0.5 * acceleration * accelTime * accelTime;

    // Determine if there's a cruise phase
    float cruiseDist = steps_rounded - 2 * accelDist;
    bool hasCruise = cruiseDist > 0;

    while (stepsTaken < steps_rounded) {
        currentTime = micros();

        // Determine current speed based on phase
        float phaseTime;
        if (stepsTaken < accelDist) {
            // Acceleration phase
            phaseTime = sqrt(2.0 * stepsTaken / acceleration);
            currentSpeed = acceleration * phaseTime;
        } else if (hasCruise && stepsTaken < (steps_rounded - accelDist)) {
            // Cruising at target speed
            currentSpeed = targetSpeed;
        } else {
            // Deceleration phase
            int stepsRemaining = steps_rounded - stepsTaken;
            phaseTime = sqrt(2.0 * stepsRemaining / acceleration);
            currentSpeed = acceleration * phaseTime;
        }

        // Avoid division by zero or too slow speeds
        if (currentSpeed < 1) currentSpeed = 1;

        stepInterval = 1000000.0 / currentSpeed;

        if ((micros() - lastStepTime) >= stepInterval) {
            // Perform step pulse
            lastStepTime = micros();
            digitalWrite(step_pin, HIGH);
            delayMicroseconds(4);
            digitalWrite(step_pin, LOW);
            stepsTaken++;
        }
    }

    // Update the current position depending on the direction
    if(direction) {
      current_position -= angle; // Update the current position in degrees
    } else {
      current_position += angle; // Update the current position in degrees
    }

    // Ensure the current position rolls over within the range [0, 360)
    while (current_position < 0) {
      current_position += 360;
    }
    while (current_position >= 360) {
      current_position -= 360;
    }
  }

  void STEPPER::move(float targetSpeed, float acceleration, float angle, int steps_revolution, STEPPER* stepper2, int stepper2_ratio) {
    float currentSpeed = 0;
    float stepInterval = 0;
    unsigned long lastStepTime = 0;
    unsigned long currentTime;
    int stepsTaken = 0;
    bool updatedStepper2Direction = false;

    //Check if stpper2 is set to rotate in the same direction
    if (stepper2->GetDirection() == direction) {
      stepper2->SetDirection(!direction);
      updatedStepper2Direction = true;
    }
  
    // Convert angle to steps
    float steps_degree = (float)steps_revolution / 360.0;
    float steps = angle * steps_degree;
    steps += steps_remainder;
    int steps_rounded = (int)floorf(steps);
    steps_remainder = steps - steps_rounded;

    if (steps_rounded <= 0) return; // No movement needed

    // Compute max reachable speed for triangular profile
    float maxReachableSpeed = sqrt(acceleration * steps_rounded);

    // Limit target speed if we don't have enough steps to reach it
    if (targetSpeed > maxReachableSpeed) {
        targetSpeed = maxReachableSpeed;
    }

    // Now compute acceleration distance for (possibly reduced) targetSpeed
    float accelTime = targetSpeed / acceleration;
    float accelDist = 0.5 * acceleration * accelTime * accelTime;
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
